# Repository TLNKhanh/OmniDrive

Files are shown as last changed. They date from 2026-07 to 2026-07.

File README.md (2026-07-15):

# OmniDrive

Dual H-bridge motor driver + ESP32 + USB-C PD, squeezed into a 45×59.5mm 2-layer board.

I wanted a board that could work with a single USB-C port and have it drive two motors (or 2 pairs if configured) while able to measure the board's current draw.

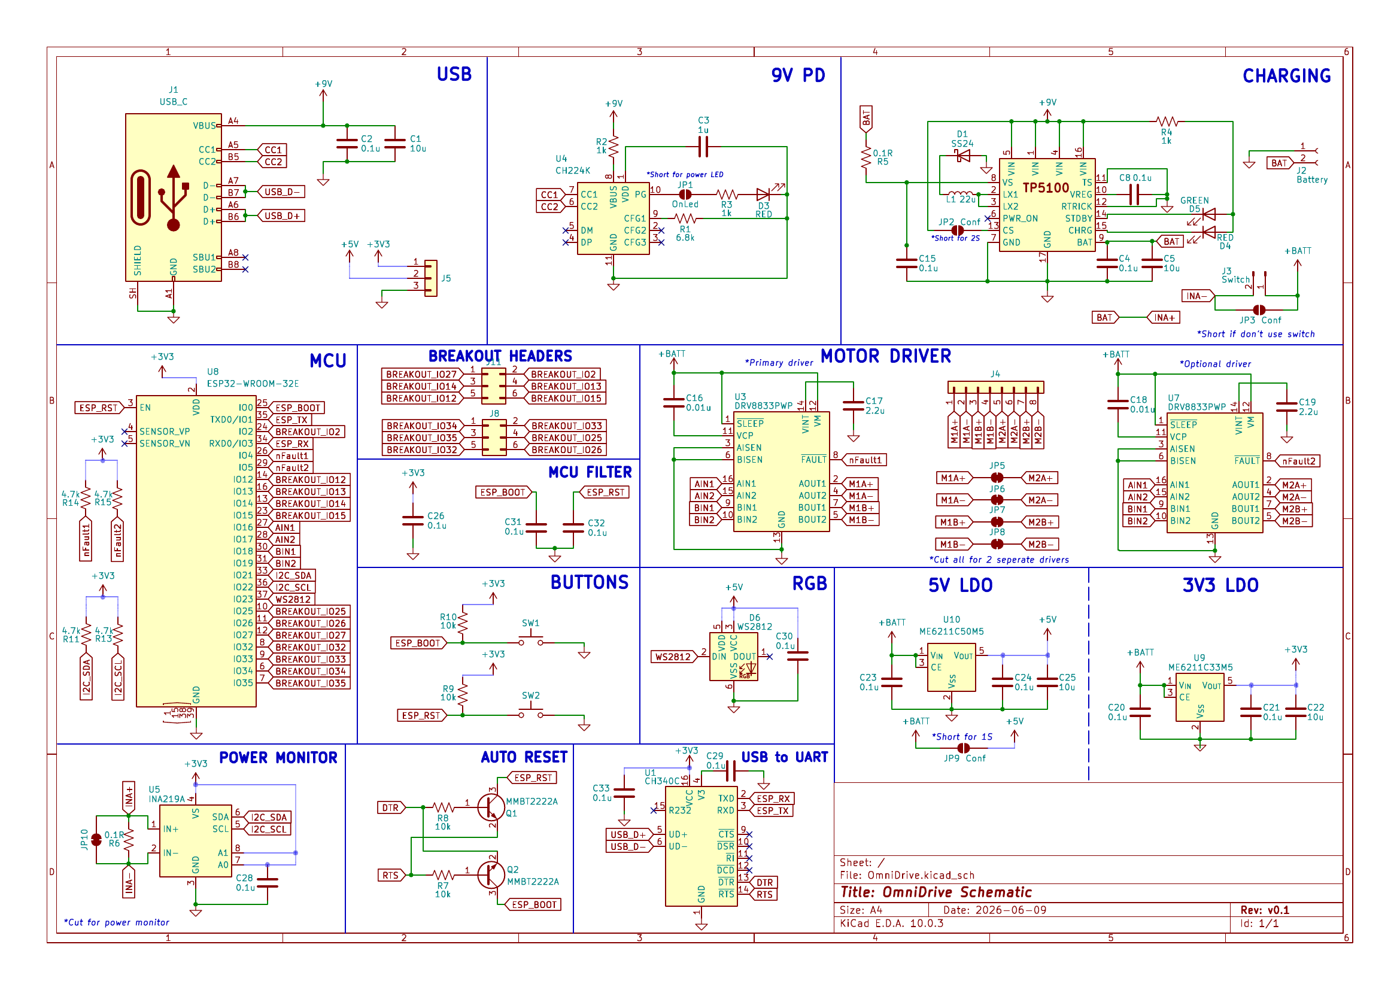
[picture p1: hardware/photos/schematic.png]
schematic

*Full schematic — click image or [open PDF](hardware/schematic.pdf)*

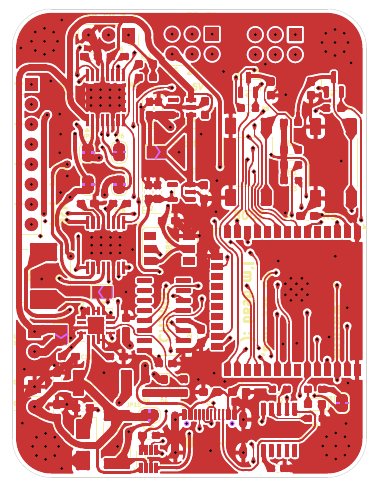
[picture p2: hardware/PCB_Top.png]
pcb_top

*PCB top copper layer — [open PDF](hardware/PCB_Top.pdf)*

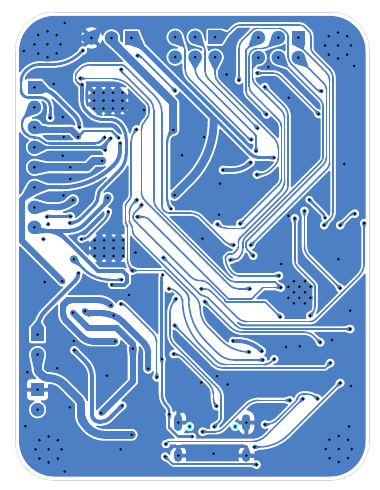
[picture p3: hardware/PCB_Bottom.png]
pcb_bottom

*PCB bottom copper layer — [open PDF](hardware/PCB_Bottom.pdf)*

## What it does

- Drives 2 or 4 DC motors (configurable) with two DRV8833 H-bridges, one DRV8833 is optimal, up to 1.5A per channel.
- Negotiates power over USB-C via CH224K to get 9V from power supply
- Measures total motor current with an INA219 over I2C
- Lets you program the ESP32 over USB through the CH340C, with automatic boot/reset
- Breaks out power lines and 14 GPIOs + I2C on a header for sensors, encoders, whatever
- Configurable 2S / 1S battery pack via solder pads

## Why I built it

I wanted something that could serve for multiple RC car or stepper driving projects without having to combine separate modules.

## Specs

| Function| Component |
|---|---|
| MCU | ESP32-WROOM-32E |
| Motor drivers | 2× DRV8833 (HTSSOP-16 with thermal pad) |
| USB-C PD | CH224K sink, negotiates 9V |
| Current sense | INA219, 0.1Ω shunt, I2C |
| USB-UART | CH340C with auto DTR/RTS |
| Logic power | ME6211C50 (5V), ME6211C33 (3.3V) |
| Breakout | 12 GPIO through 2x 3x2 header, Power through 1x 3x1 header|
| PCB | 2-layer, 1.6mm FR4, 45×59.5mm |

## Power flow

USB-C VBUS → CH224K negotiates voltage → +BATT rail

+BATT splits three ways:
- Directly to the DRV8833 motor drivers
- Through a 5V LDO (ME6211C50) for the CH340C and other devices
- It also then goes through a 3.3V LDO (ME6211C33) for the ESP32, INA219, WS2812,...

Motor current goes through a shared 0.1Ω sense resistor before reaching the drivers, so the INA219 sees total bus current. Per-motor would need two INA219s (maybe for later).

## Known issues / things to fix

A few things I'll change next version:

- The ME6211C33 is rated for 500mA and ESP32 can spike past that during WiFi TX. On a long USB-C cable with some voltage drop, the battery rail might sag enough to make the 3.3V regulator drop out. An AP2112 or similar low-dropout part would be safer.

- Didn't add TVS diodes on the USB-C CC/D+/D- lines or the motor outputs

- As mentioned, only total motor current. Can't tell which motor is drawing what.

## Files in hardware/

```
hardware/
├── schematic.pdf          — full schematic (click to view)
├── PCB_Top.pdf            — top copper render
├── PCB_Bottom.pdf         — bottom copper render
├── gerbers.zip            — Gerbers + drill files
├── bom.csv                — BOM for JLCPCB assembly
├── pick-place.csv         — centroid file
├── kicad/                 — source KiCad project
└── photos/                — PNG renders of schematic + PCB
```

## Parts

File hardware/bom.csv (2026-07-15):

Reference | Value | Footprint | LCSC Part # | DNP
C1,C5,C22,C25 | 10u | Capacitor_SMD:C_0603_1608Metric_Pad1.08x0.95mm_HandSolder
C2,C4,C8,C15,C20,C21,C23,C24,C26,C28-C33 | 0.1u | Capacitor_SMD:C_0603_1608Metric_Pad1.08x0.95mm_HandSolder
C3 | 1u | Capacitor_SMD:C_0603_1608Metric_Pad1.08x0.95mm_HandSolder
C16,C18 | 0.01u | Capacitor_SMD:C_0603_1608Metric_Pad1.08x0.95mm_HandSolder
C17,C19 | 2.2u | Capacitor_SMD:C_0603_1608Metric_Pad1.08x0.95mm_HandSolder
D1 | SS24 | Diode_SMD:D_SMA
D3,D4 | RED | LED_SMD:LED_0603_1608Metric_Pad1.05x0.95mm_HandSolder
D5 | GREEN | LED_SMD:LED_0603_1608Metric_Pad1.05x0.95mm_HandSolder
D6 | WS2812 | LED_SMD:LED_WS2812_PLCC6_5.0x5.0mm_P1.6mm
J1 | USB_C | Connector_USB:USB_C_Receptacle_HCTL_HC-TYPE-C-16P-01A
J2 | Battery | Connector_PinHeader_2.54mm:PinHeader_1x02_P2.54mm_Vertical
J3 | Switch | Connector_PinHeader_2.54mm:PinHeader_1x02_P2.54mm_Vertical
J4 | Conn_01x08 | Connector_PinSocket_2.54mm:PinSocket_1x08_P2.54mm_Vertical
J5 | Conn_01x03 | Connector_PinSocket_2.54mm:PinSocket_1x03_P2.54mm_Vertical
J8,J11 | Conn_02x03_Odd_Even | Connector_PinHeader_2.54mm:PinHeader_2x03_P2.54mm_Vertical
L1 | 22u | Inductor_SMD:L_Changjiang_FXL0630
Q1,Q2 | MMBT2222A | Package_TO_SOT_SMD:SOT-23
R1 | 6.8k | Resistor_SMD:R_0603_1608Metric_Pad0.98x0.95mm_HandSolder
R2-R4 | 1k | Resistor_SMD:R_0603_1608Metric_Pad0.98x0.95mm_HandSolder
R5,R6 | 0.1R | Resistor_SMD:R_2512_6332Metric_Pad1.40x3.35mm_HandSolder
R7-R10 | 10k | Resistor_SMD:R_0603_1608Metric_Pad0.98x0.95mm_HandSolder
R11,R13-R15 | 4.7k | Resistor_SMD:R_0603_1608Metric_Pad0.98x0.95mm_HandSolder
SW1,SW2 | SW_Push | Button_Switch_SMD:SW_Push_1P1T_NO_E-Switch_TL3301NxxxxxG
U1 | CH340C | Package_SO:SOIC-16_3.9x9.9mm_P1.27mm
U2 |  | Package_DFN_QFN:NXP_VQFN-16-1EP_4x4mm_P0.65mm_EP2.1x2.1mm
U3,U7 | DRV8833PWP | Package_SO:HTSSOP-16-1EP_4.4x5mm_P0.65mm_EP3.4x5mm_Mask2.46x2.31mm_ThermalVias
U4 | CH224K | Package_SO:SSOP-10-1EP_3.9x4.9mm_P1mm_EP2.1x3.3mm
U5 | INA219A | Package_TO_SOT_SMD:SOT-23-8
U8 | ESP32-WROOM-32E | RF_Module:ESP32-WROOM-32E
U9 | ME6211C33M5 | Package_TO_SOT_SMD:SOT-23-5
U10 | ME6211C50M5 | Package_TO_SOT_SMD:SOT-23-5

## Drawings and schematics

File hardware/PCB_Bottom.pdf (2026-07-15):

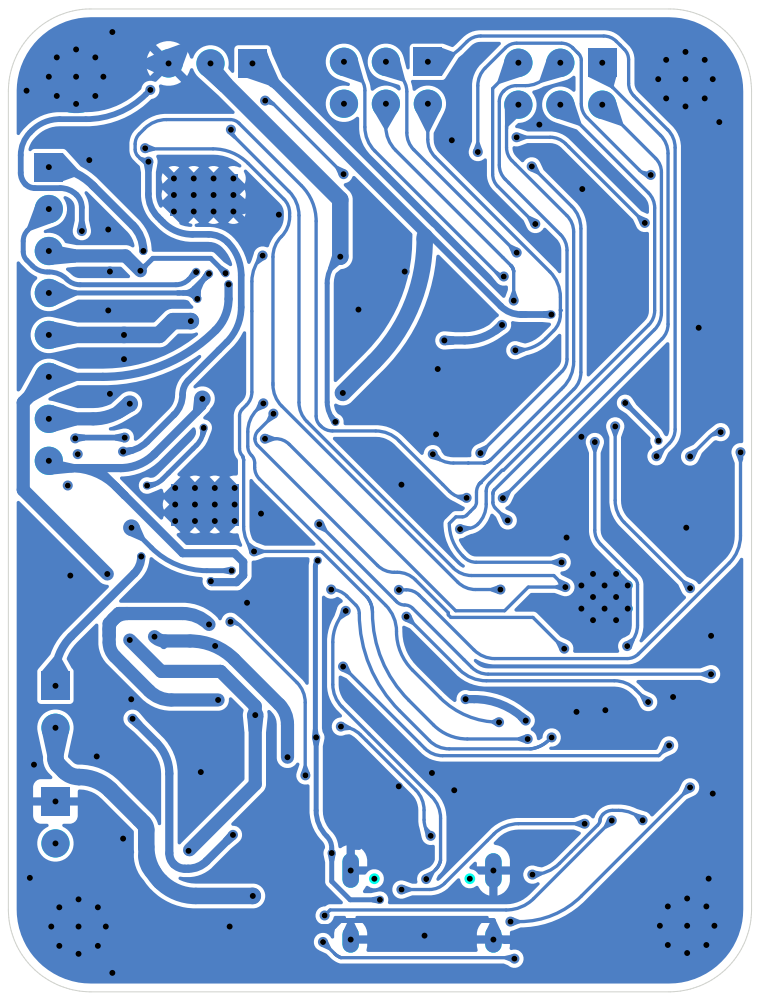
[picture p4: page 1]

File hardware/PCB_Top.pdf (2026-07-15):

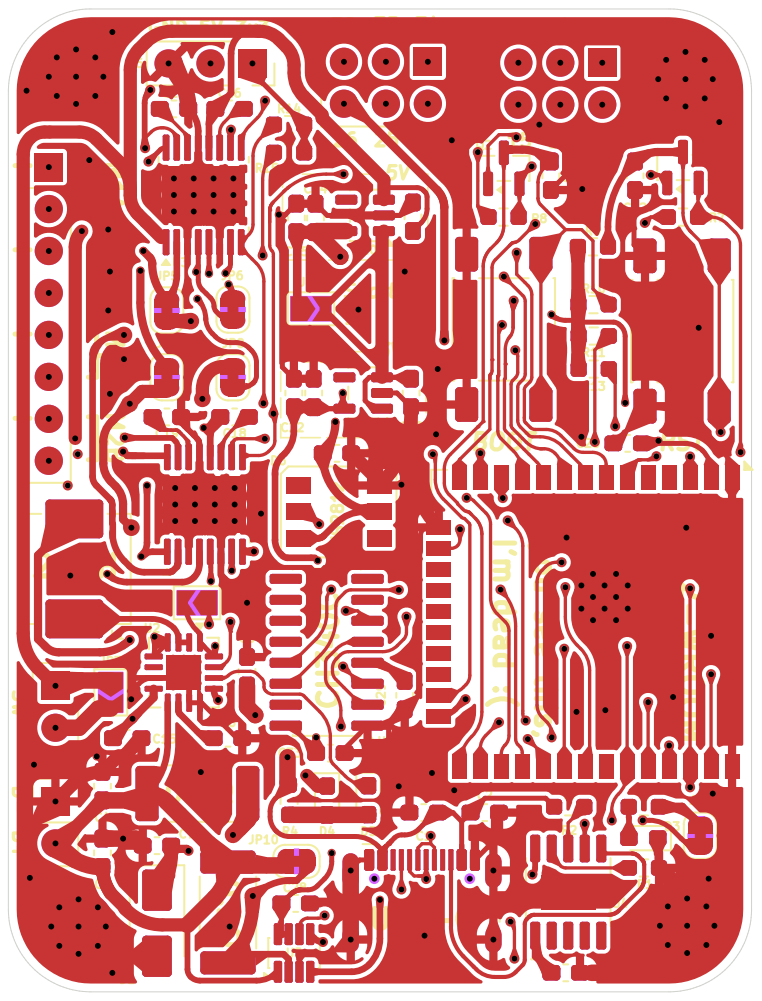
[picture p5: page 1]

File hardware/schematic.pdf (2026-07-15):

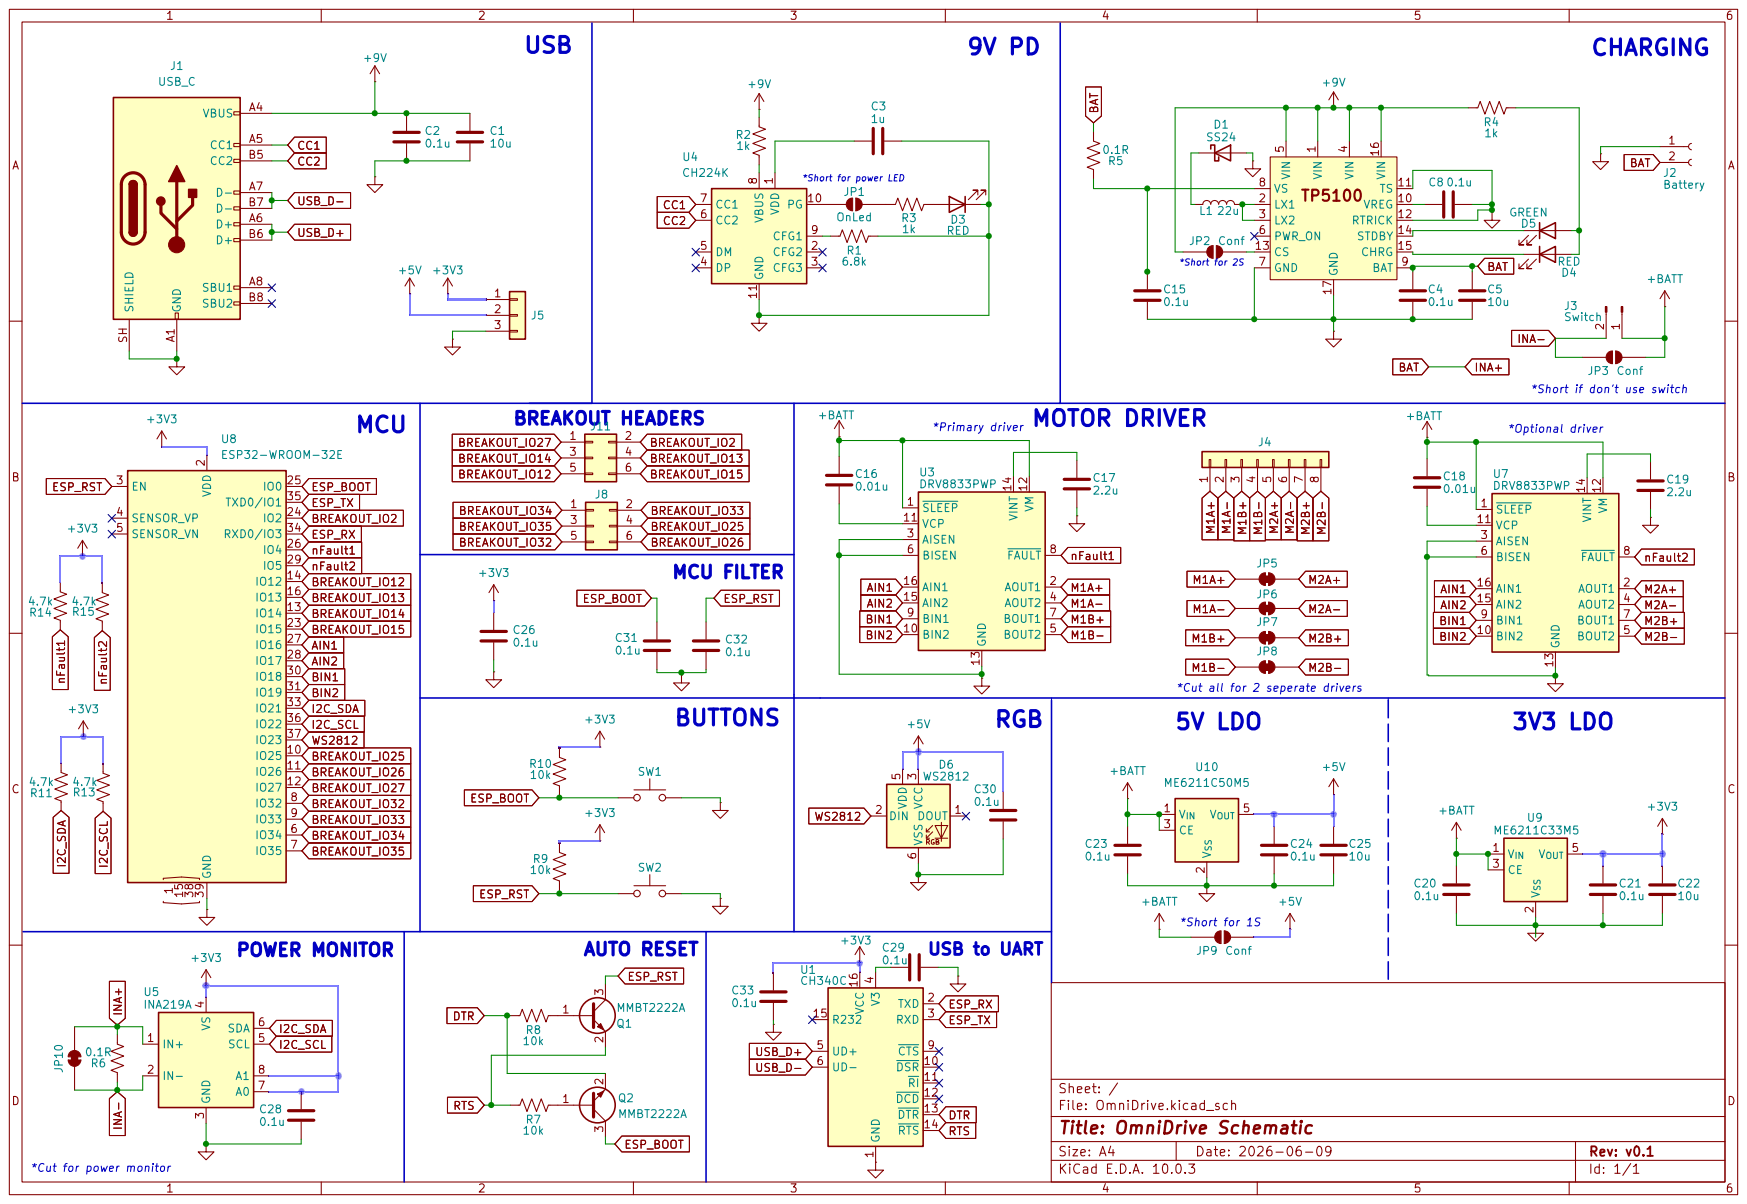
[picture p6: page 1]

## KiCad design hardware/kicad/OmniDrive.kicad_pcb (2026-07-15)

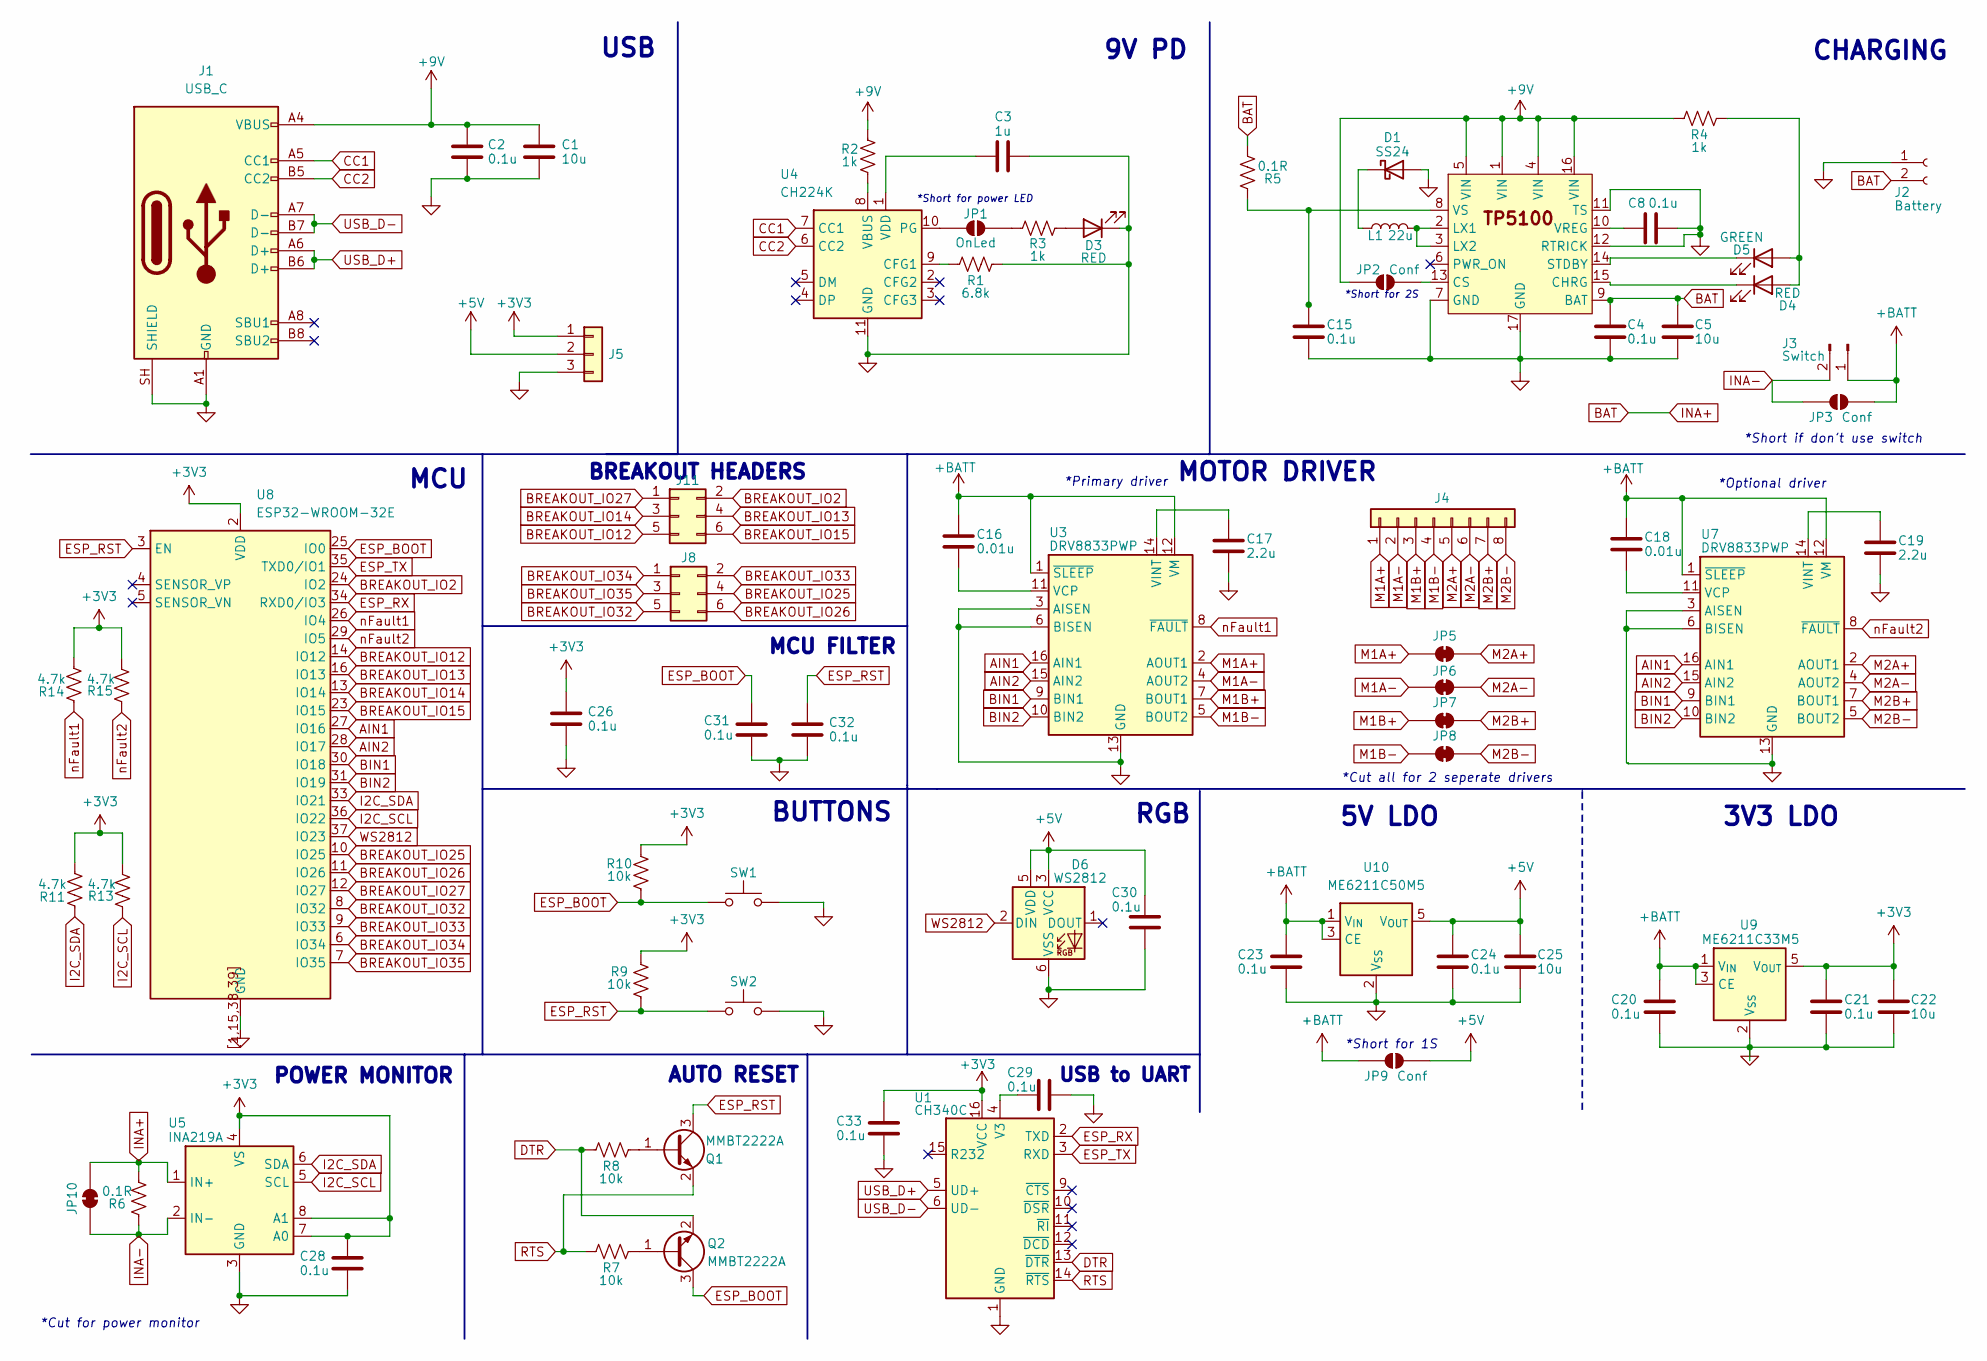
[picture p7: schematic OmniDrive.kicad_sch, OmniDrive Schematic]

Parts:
C1, C5, C22, C25: 10u; C_0603_1608Metric_Pad1.08x0.95mm_HandSolder
C2, C4, C8, C15, C20, C21, C23, C24, C26, C28, C29, C30, C31, C32, C33: 0.1u; C_0603_1608Metric_Pad1.08x0.95mm_HandSolder
C3: 1u; C_0603_1608Metric_Pad1.08x0.95mm_HandSolder
C16, C18: 0.01u; C_0603_1608Metric_Pad1.08x0.95mm_HandSolder
C17, C19: 2.2u; C_0603_1608Metric_Pad1.08x0.95mm_HandSolder
D1: SS24; D_SMA
D3, D4: RED; LED_0603_1608Metric_Pad1.05x0.95mm_HandSolder
D5: GREEN; LED_0603_1608Metric_Pad1.05x0.95mm_HandSolder
D6: WS2812; LED_WS2812_PLCC6_5.0x5.0mm_P1.6mm
J1: USB_C; USB_C_Receptacle_HCTL_HC-TYPE-C-16P-01A
J2: Battery; PinHeader_1x02_P2.54mm_Vertical
J3: Switch; PinHeader_1x02_P2.54mm_Vertical
J4: Conn_01x08; PinSocket_1x08_P2.54mm_Vertical
J5: Conn_01x03; PinSocket_1x03_P2.54mm_Vertical
J8, J11: Conn_02x03_Odd_Even; PinHeader_2x03_P2.54mm_Vertical
JP1: OnLed; SolderJumper-2_P1.3mm_Bridged_RoundedPad1.0x1.5mm
JP2, JP3, JP9: Conf; SolderJumper-2_P1.3mm_Open_TrianglePad1.0x1.5mm
JP5, JP6, JP7, JP8, JP10: BridgedJumper; SolderJumper-2_P1.3mm_Bridged_RoundedPad1.0x1.5mm
L1: 22u; L_Changjiang_FXL0630
Q1, Q2: MMBT2222A; SOT-23
R1: 6.8k; R_0603_1608Metric_Pad0.98x0.95mm_HandSolder
R2, R3, R4: 1k; R_0603_1608Metric_Pad0.98x0.95mm_HandSolder
R5, R6: 0.1R; R_2512_6332Metric_Pad1.40x3.35mm_HandSolder
R7, R8, R9, R10: 10k; R_0603_1608Metric_Pad0.98x0.95mm_HandSolder
R11, R13, R14, R15: 4.7k; R_0603_1608Metric_Pad0.98x0.95mm_HandSolder
SW1, SW2: SW_Push; SW_Push_1P1T_NO_E-Switch_TL3301NxxxxxG
U1: CH340C; SOIC-16_3.9x9.9mm_P1.27mm
U2: NXP_VQFN-16-1EP_4x4mm_P0.65mm_EP2.1x2.1mm
U3, U7: DRV8833PWP; HTSSOP-16-1EP_4.4x5mm_P0.65mm_EP3.4x5mm_Mask2.46x2.31mm_The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
U4: CH224K; SSOP-10-1EP_3.9x4.9mm_P1mm_EP2.1x3.3mm
U5: INA219A; SOT-23-8
U8: ESP32-WROOM-32E
U9: ME6211C33M5; SOT-23-5
U10: ME6211C50M5; SOT-23-5

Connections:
+3V3: C21.1, C22.1, C26.1, C28.1, C33.2, J5.1, R9.1, R10.1, R11.2, R13.2, R14.2, R15.2, U1.16 (VCC), U5.4 (VS), U5.7 (A0), U5.8 (A1), U8.2 (VDD), U9.5 (V_{OUT})
+5V: C24.1, C25.1, C30.1, D6.3 (VCC), D6.5 (VDD), J5.2, JP9.1 (A), U10.5 (V_{OUT})
+9V: C1.1, C2.1, J1.A4 (VBUS), J1.A9 (VBUS), J1.B4 (VBUS), J1.B9 (VBUS), JP2.2 (B), R2.2, R4.2, U2.1 (VIN), U2.4 (VIN), U2.5 (VIN), U2.16 (VIN)
+BATT: C16.1, C18.1, C20.1, C23.1, J3.1, JP3.1 (A), JP9.2 (B), U3.1 (~SLEEP), U3.12 (VM), U7.1 (~SLEEP), U7.12 (VM), U9.1 (V_{IN}), U9.3 (CE), U10.1 (V_{IN}), U10.3 (CE)
AIN1: U3.16 (AIN1), U7.16 (AIN1), U8.27 (IO16)
AIN2: U3.15 (AIN2), U7.15 (AIN2), U8.28 (IO17)
BAT: C4.1, C5.1, J2.2, JP10.2 (B), R5.1, R6.1, U2.9 (BAT), U5.1 (IN+)
BIN1: U3.9 (BIN1), U7.9 (BIN1), U8.30 (IO18)
BIN2: U3.10 (BIN2), U7.10 (BIN2), U8.31 (IO19)
BREAKOUT_IO2: J11.2, U8.24 (IO2)
BREAKOUT_IO12: J11.5, U8.14 (IO12)
BREAKOUT_IO13: J11.4, U8.16 (IO13)
BREAKOUT_IO14: J11.3, U8.13 (IO14)
BREAKOUT_IO15: J11.6, U8.23 (IO15)
BREAKOUT_IO25: J8.4, U8.10 (IO25)
BREAKOUT_IO26: J8.6, U8.11 (IO26)
BREAKOUT_IO27: J11.1, U8.12 (IO27)
BREAKOUT_IO32: J8.5, U8.8 (IO32)
BREAKOUT_IO33: J8.2, U8.9 (IO33)
BREAKOUT_IO34: J8.1, U8.6 (IO34)
BREAKOUT_IO35: J8.3, U8.7 (IO35)
CC1: J1.A5 (CC1), U4.7 (CC1)
CC2: J1.B5 (CC2), U4.6 (CC2)
DTR: Q2.2 (E), R8.2, U1.13 (~DTR)
ESP_BOOT: C31.1, Q2.3 (C), R10.2, SW1.1, U8.25 (IO0)
ESP_RST: C32.1, Q1.3 (C), R9.2, SW2.1, U8.3 (EN)
ESP_RX: U1.2 (TXD), U8.34 (RXD0/IO3)
ESP_TX: U1.3 (RXD), U8.35 (TXD0/IO1)
GND: C1.2, C2.2, C3.1, C4.2, C5.2, C8.2, C15.2, C17.2, C19.2, C20.2, C21.2, C22.2, C23.2, C24.2, C25.2, C26.2, C28.2, C29.1, C30.2, C31.2, C32.2, C33.1, D1.2 (A), D3.1 (K), D6.6 (VSS), J1.A1 (GND), J1.A12 (GND), J1.B1 (GND), J1.B12 (GND), J1.SH (SHIELD), J2.1, J5.3, R1.1, SW1.2, SW2.2, U1.1 (GND), U2.7 (GND), U2.11 (TS), U2.12 (RTRICK), U2.17 (GND), U3.3 (AISEN), U3.6 (BISEN), U3.13 (GND), U3.17 (GND), U4.11 (GND), U5.3 (GND), U7.3 (AISEN), U7.6 (BISEN), U7.13 (GND), U7.17 (GND), U8.1 (GND), U8.15 (GND), U8.38 (GND), U8.39 (GND), U8.[1,15,38,39] (GND), U9.2 (V_{SS}), U10.2 (V_{SS}); also elsewhere on the board
I2C_SCL: R13.1, U5.5 (SCL), U8.36 (IO22)
I2C_SDA: R11.1, U5.6 (SDA), U8.33 (IO21)
INA-: J3.2, JP3.2 (B), JP10.1 (A), R6.2, U5.2 (IN-)
M1A+: J4.1, JP5.1 (A), U3.2 (AOUT1)
M1A-: J4.2, JP6.1 (A), U3.4 (AOUT2)
M1B+: J4.3, JP7.1 (A), U3.7 (BOUT1)
M1B-: J4.4, JP8.1 (A), U3.5 (BOUT2)
M2A+: J4.5, JP5.2 (B), U7.2 (AOUT1)
M2A-: J4.6, JP6.2 (B), U7.4 (AOUT2)
M2B+: J4.7, JP7.2 (B), U7.7 (BOUT1)
M2B-: J4.8, JP8.2 (B), U7.5 (BOUT2)
unnamed 40: D1.1 (K), L1.1; also elsewhere on the board
unnamed: D3.2 (A), R3.1
unnamed: D4.2 (A), D5.2 (A), R4.1
unnamed: D4.1 (K), U2.15 (CHRG)
unnamed: D5.1 (K), U2.14 (STDBY)
unnamed: JP1.1 (A), R3.2
unnamed: JP1.2 (B), U4.10 (PG)
unnamed: JP2.1 (A), U2.13 (CS)
unnamed: Q1.1 (B), R8.1
unnamed: Q2.1 (B), R7.1
unnamed: C29.2, U1.4 (V3)
unnamed: L1.2, U2.2 (LX1), U2.3 (LX2)
unnamed: C8.1, U2.10 (VREG)
unnamed: C15.1, R5.2, U2.8 (VS)
unnamed: C16.2, U3.11 (VCP)
unnamed: C17.1, U3.14 (VINT)
unnamed: R1.2, U4.9 (CFG1)
unnamed: R2.1, U4.8 (VBUS)
unnamed: C3.2, U4.1 (VDD)
unnamed: C18.2, U7.11 (VCP)
unnamed: C19.1, U7.14 (VINT)
RTS: Q1.2 (E), R7.2, U1.14 (~RTS)
USB_D+: J1.A6 (D+), J1.B6 (D+), U1.5 (UD+)
USB_D-: J1.A7 (D-), J1.B7 (D-), U1.6 (UD-)
WS2812: D6.2 (DIN), U8.37 (IO23)
nFault1: R14.1, U3.8 (~FAULT), U8.26 (IO4)
nFault2: R15.1, U7.8 (~FAULT), U8.29 (IO5)

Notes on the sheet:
*Short for 1S
*Short for power LED
BREAKOUT HEADERS
*Short for 2S
3V3 LDO
POWER MONITOR
RGB
BUTTONS
*Primary driver
*Short if don't use switch
CHARGING
*Cut all for 2 seperate drivers
AUTO RESET
USB to UART
MCU
MOTOR DRIVER
5V LDO
USB
*Cut for power monitor
*Optional driver
9V PD
MCU FILTER

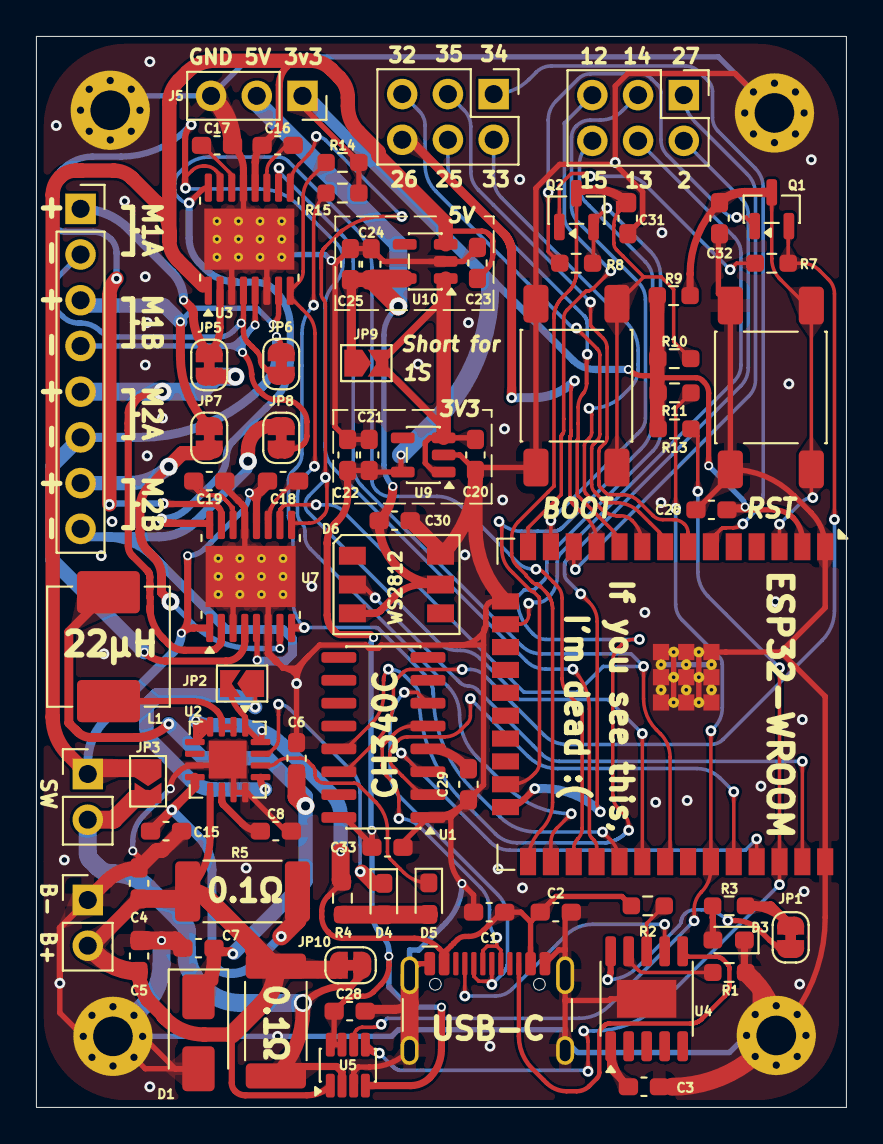
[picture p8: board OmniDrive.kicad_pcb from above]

Board: 2 copper layers, 45.0 x 59.5 mm, 79 parts (0 on the bottom side), 67 nets.

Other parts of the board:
C6: 0.1u; C_0603_1608Metric_Pad1.08x0.95mm_HandSolder
C7: 10u; C_0603_1608Metric_Pad1.08x0.95mm_HandSolder
HoleA: MountingHole_2.2mm_M2_Pad_Via
HoleB: MountingHole_2.2mm_M2_Pad_Via
HoleC: MountingHole_2.2mm_M2_Pad_Via
HoleD: MountingHole_2.2mm_M2_Pad_Via

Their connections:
GND: C6.2, C7.2, HoleA.1, HoleB.1, HoleC.1, HoleD.1; also elsewhere on the board
unnamed 40: C6.1, C7.1; also elsewhere on the board

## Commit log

2026-07-15 Initial hardware release: schematic, gerbers, BOM, CPL, KiCad project
    [OmniDrive-B_Cu.gbr, OmniDrive-B_Mask.gbr, OmniDrive-B_Paste.gbr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]
2026-07-15 Add 3 PDFs (schematic, PCB front/back) to hardware/ and update README
2026-07-15 Add PNG renders of schematic and PCB to README
2026-07-15 Ignore KiCad .lck lock files
2026-07-15 Add captions under schematic and PCB images
2026-07-15 Replace PCB PDFs with updated PNG renders
2026-07-15 Update README: clickable schematic image links to PDF
2026-07-15 Add clickable PDF links for PCB images too
2026-07-15 Update PCB PDFs, clean up stale renders
2026-07-15 Add PCB PNG copies to photos/
2026-07-15 Update README: breakout spec, fix front→top
